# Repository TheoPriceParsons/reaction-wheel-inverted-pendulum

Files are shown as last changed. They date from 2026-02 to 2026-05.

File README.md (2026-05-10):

# Reaction-Wheel Inverted Pendulum

A reaction-wheel-actuated pendulum stabilised at its unstable upright equilibrium using a two-phase controller: bang-bang energy shaping for swing-up and a discrete LQR with Luenberger observer for stabilisation. Implemented on an STM32F446RE Nucleo running at 500 Hz using STM32 HAL.

> **Status:** Simulation complete. Hardware build in progress.

**TODO: UPDATE FIRMWARE WITH SIM CONSTANTS**

---

## Demo

*Video coming once hardware build is complete.*

Simulation result (30 s run, $\theta_0 = 0.1$ rad):

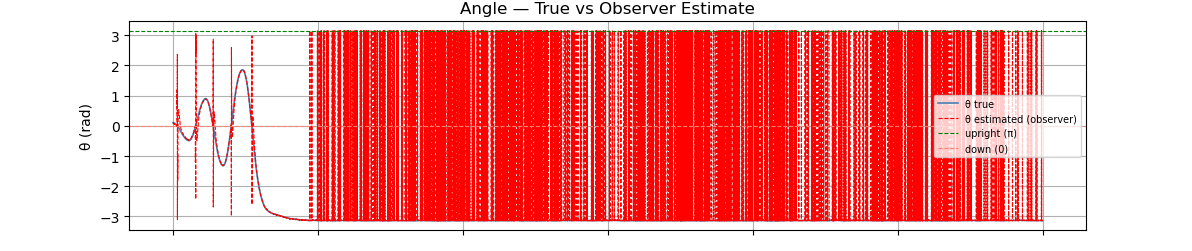
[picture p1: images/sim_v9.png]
Simulation


---

## Why This Problem Is Hard

The system has two degrees of freedom (pendulum angle $\theta$, wheel angle $\varphi$) but only one control input (motor torque $\tau$). This underactuation means a single controller cannot handle the full range of motion:

- **Large angles:** the linearisation breaks down entirely — $\sin\theta \neq \theta$
- **Near upright:** the equilibrium is open-loop unstable (eigenvalues $\pm 5.7$ rad/s)
- **No velocity sensor:** $\dot{\theta}$ is not directly measured; it must be estimated

A single LQR cannot swing the pendulum up from rest. A single energy controller cannot stabilise the upright. The solution requires two controllers and a principled switch between them.

---

## Controller Design

### Phase 1 — Bang-Bang Swing-Up

A bang-bang energy pump drives the pendulum from rest toward the upright equilibrium. The control law applies full motor voltage in the direction that adds mechanical energy:

$$
\tau = \begin{cases} -V_{\text{supply}} \cdot \text{sign}(\dot{\theta}) & \text{if } E < E^* \\ 0 & \text{if } E \geq E^* \end{cases}
$$

where $E^* = mgl$ is the target energy (upright with zero velocity) and the current energy is:

$$E = \tfrac{1}{2}ml^2\dot{\theta}^2 - mgl\cos\theta$$

Torque is cut once sufficient energy has accumulated; the pendulum coasts toward the top where LQR engages. A small initial kick ($0.3 \cdot V_{\text{supply}}$) handles the degenerate case where $\dot{\theta} \approx 0$ at startup.

### Phase 2 — Discrete LQR

Near the upright equilibrium, the nonlinear system is linearised by substituting $\delta = \theta - \pi$ (deviation from upright) and using $\sin(\pi + \delta) \approx -\delta$:

$$\ddot{\delta} \approx \frac{g}{l}\delta - \frac{2}{ml^2}\tau$$

This gives a 2-state controllable system $\mathbf{x} = [\delta,\; \dot{\delta}]^\top$. The LQR minimises:

$$J = \sum \left(\mathbf{x}^\top Q\mathbf{x} + R\tau^2\right)$$

with $Q = \text{diag}(300,\, 10)$, $R = 1$. The plant is discretised via zero-order hold at 500 Hz before solving the discrete algebraic Riccati equation.

**Why not design LQR on the full 3-state system $[\theta,\, \dot{\theta},\, \dot{\varphi}]$?** The controllability matrix of the full system has rank 2 — $\dot{\varphi}$ is uncontrollable from $\tau$. Including it in the LQR produces a spurious gain on an unobservable state.

### Switching Condition

LQR engages when both:
- $|\hat{\delta}| < 0.5$ rad (estimated deviation from upright)
- $|\dot{\hat{\delta}}| < 4.0$ rad/s (estimated angular velocity)

Estimates come from the Luenberger observer, not raw measurements.

### Luenberger Observer

The encoder measures $\theta$ with noise ($\sigma \approx 0.02$ rad). Angular velocity $\dot{\theta}$ is not directly sensed. A discrete Luenberger observer runs at 500 Hz alongside the controller:

$$
\begin{aligned}
\hat{\mathbf{x}}[k+1] &= A_d\hat{\mathbf{x}}[k] + B_d\tau[k] \quad \text{(prediction)}\\
\hat{\mathbf{x}}[k] &= \hat{\mathbf{x}}[k] + L\!\left(\delta_{\text{meas}} - \hat{x}_0[k]\right) \quad \text{(correction)}
\end{aligned}
$$

Observer poles are placed at $z = e^{-40\,\Delta t}$ and $z = e^{-60\,\Delta t}$ — roughly 3–5× faster than the closed-loop poles, following standard observer design rules. This gives the observer gain $L = [0.190,\; 4.562]^\top$.

The observer is what makes the LQR switching condition reliable. Using raw encoder position alone to decide when to switch would cause false triggers from measurement noise.

---

## Hardware

| Part | Qty | Notes |
|---|-----|---|
| STM32F446RE Nucleo-64 | 1 | Already owned |
| Pololu 9.7:1 Metal Gearmotor 25Dx63L mm HP 12V with 48 CPR Encoder (item #4842) | 1 | 9.68:1 gearbox, 4mm D-shaft output, integrated Hall effect quadrature encoder (464.64 CPR at output shaft) |
| Pololu Universal Aluminum Mounting Hub for 4mm Shaft, M3 Holes (item #1997) | 1 | Attaches reaction wheel to gearmotor output shaft via set screw |
| VNH5019 Motor Driver Carrier (Pololu item #1451) | 1 | Handles up to 12A continuous, recommended for HP 25D series |
| AMT103-V encoder kit | 1 | Quadrature A/B mode, DIP switch position 10 = 2048 PPR. Used at pivot to measure $\theta$. The -V suffix means it ships with all sleeve sizes (2–8 mm) — use the sleeve matching your pivot shaft |
| 12V 2A power supply | 1 | Start at 3V during bring-up |

### Physical Parameters

| Parameter | Value | Notes |
|---|---|---|
| Pendulum length $l$ | 0.1 m | Pivot to motor shaft center |
| Bob mass $m$ | 0.25 kg | Estimated; update from CAD once built |
| Wheel inertia $I_w$ | 0.0003 kg·m² | From Onshape mass properties |
| Damping $b$ | 0.01 N·m·s/rad | Viscous friction estimate |

### Motor Parameters (Pololu #4842, referred to output shaft)

| Parameter | Value | Source |
|---|---|---|
| $V_{\text{supply}}$ | 12.0 V | Rated |
| $R_m$ (winding resistance) | 2.4 Ω | $V / I_{\text{stall}} = 12.0 / 5.0$ |
| $K_t$ (torque constant) | 0.0762 N·m/A | $\tau_{\text{stall}} / I_{\text{stall}} = 0.3812 / 5.0$ |
| $K_e$ (back-EMF constant) | 0.0762 V·s/rad | $\approx K_t$ at output shaft |
| $\eta$ (gearbox efficiency) | 0.52 | Datasheet max efficiency |
| Stall torque @ 12V (effective) | 0.198 Nm | $\eta \cdot K_t \cdot V / R_m$ |

**These will be verified on hardware** before final controller tuning. $K_t$ in particular should be measured directly.

---

## Repository Structure

```
├── report.pdf                          Full derivation (Lagrangian, LQR, observer design)
├── simulations/
│   └── Sim_v9_added-discretization.ipynb   Simulation with plots
├── Software/
│   └── pendulum_main.ino               Older simple FOC implementation used as a basis
│   └── pendulum_main_arduino           All components for STM32 HAL abstraction level
└── README.md
```

### Simulation

```bash
pip install numpy scipy matplotlib control
```

### Firmware

Firmware is written in STM32 HAL. The Arduino implementation is left as a starting point reference.

## Firmware Constants

Gains from simulation v9 — to be recomputed once real $m$ and $I_w$ are confirmed from hardware:

```c
const float Kd[2]    = {-3.403565f, -0.605939f};
const float Ad[2][2] = {{1.000196f, 0.002000f}, {0.196213f, 1.000196f}};
const float Bd[2]    = {-0.001600f, -1.600105f};
const float Ld[2]    = {0.190356f,  4.561568f};
const float dt       = 0.0020f;  // 500 Hz
```

---

## Design Decisions

**Why a Luenberger observer rather than a complementary filter?**

A complementary filter on encoder + differentiated position is simple but introduces a tuning parameter (cutoff frequency) with no principled connection to the system dynamics. The Luenberger observer poles are placed explicitly relative to the closed-loop poles, and the gain derivation falls directly out of the same state-space framework used for the LQR. Everything stays consistent — physics and math throughout, no hand-tuned filters.

**Why encode $\theta$ at the pivot rather than use an IMU?**

A base encoder gives exact $\theta$ with no drift, no complementary filter, and no phase lag. The IMU approach (used in many student builds) requires careful filter tuning and introduces delay that degrades observer performance. The AMT103-V at 2048 PPR gives sub-0.2° resolution, well below the observer's assumed noise floor.

---

## Planned Extensions

- [ ] Hardware build and experimental validation
- [ ] Measure motor parameters ($K_t$, $K_e$, $R_m$) directly on hardware
- [ ] Characterise encoder noise floor (connects observer $\sigma_{\text{angle}}$ assumption to real data)
- [ ] Bare-metal STM32 HAL rewrite
- [ ] Swing-up controller refinement
- [ ] Extended Kalman Filter replacing Luenberger observer

---

## References

- [V. Hunter Adams — Reaction Wheel Pendulum Lab (Cornell)](https://vanhunteradams.com/Pico/ReactionWheel/ReactionWheel.html)
- [SimpleFOC Reaction Wheel Reference Project](https://github.com/simplefoc/Arduino-FOC-reaction-wheel-inverted-pendulum)
- [SimpleFOC Library Documentation](https://docs.simplefoc.com/)
- Åström & Furuta, *Swinging up a Pendulum by Energy Control* (1996)

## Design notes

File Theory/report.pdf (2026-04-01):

## Nonlinear Modeling, Control, and Estimation of an Underactuated Pendulum System

Theodore Price-Parsons

April 1, 2026

Abstract

This report develops a first-principles dynamic model of a reaction-wheel-actuated pendulum using Lagrangian mechanics. A state-space representation is derived and used to design a Linear Quadratic Regulator (LQR) for stabilisation near the unstable upright equilibrium. A bang-bang energy-shaping controller handles the swing-up phase. Simulation results confirm stable regulation from the downward resting position.

## 1 Problem Statement

### 1.1 System Description

A rigid pendulum is mounted on a pivot and actuated by a reaction wheel attached at its tip. The wheel is driven by a motor that applies an internal torque τ between the pendulum body and the wheel. By Newton’s third law, this torque acts equally and oppositely on both components. The system is planar and the only external force is gravity.

### 1.2 Objective

Develop a first-principles dynamic model using Lagrangian mechanics, derive a state-space representation suitable for control design, and implement a two-phase controller: (1) a bang-bang energy pump to swing the pendulum from rest to near the upright position, and (2) an LQR to stabilise the upright unstable equilibrium.

### 1.3 Why the Problem Is Nontrivial

Three sources of difficulty make this problem non-trivial:

- Nonlinearity. The governing equation contains sin θ, which is only linear near equilibrium. A linear controller alone cannot handle large-angle motion.
- Underactuation. The system has two degrees of freedom (θ and ϕ) but only one control input (τ ). The wheel angle ϕ is not independently controllable.
- Unstable equilibrium. The upright position is open-loop unstable. Any perturbation causes the pendulum to fall without active control.

## 2 Physical Model

### 2.1 Convention

Throughout this report the following angle convention is used, consistent with the simulation:

Value | Physical meaning
θ = 0 | Pendulum hanging down (stable equilibrium)
θ = π | Pendulum pointing up (unstable equilibrium, control target)

This is the natural physical convention: gravity acts to restore the pendulum toward θ = 0.

### 2.2 Assumptions

- Massless and rigid pendulum rod
- No friction, no air resistance (ideal case; extensions in Section 6)
- Planar motion only
- Ideal motor: torque τ is applied instantaneously and without loss
- Gravitational acceleration g is constant

### 2.3 Generalised Coordinates

Symbol | Description | Convention
θ | Pendulum angle measured from downward vertical | θ = 0 is down
ϕ | Reaction wheel angle relative to the pendulum body

The absolute angular position of the reaction wheel in the inertial frame is θ + ϕ.

### 2.4 Parameters

Symbol | Description | Value used
m | Pendulum bob mass | 0.5 kg
l | Pendulum length | 0.3 m
Iw | Wheel moment of inertia | 0.002 kg m²
g | Gravitational acceleration | 9.81 m/s²

## 3 Equations of Motion

### 3.1 Kinetic Energy

The system has two contributions to kinetic energy. Pendulum bob (point mass, translational):

Tpend =

1
2

ml² ˙θ
2

Reaction wheel (rotational about pivot):

Twheel =

1
2

Iw

˙θ + ϕ˙

2

Total kinetic energy:

T =

1
2

ml² ˙θ
2 +

1
2

Iw

˙θ + ϕ˙

2

### 3.2 Potential Energy

With θ = 0 defined as the downward position, the bob is at its lowest point when θ = 0 and at its highest when θ = π. The potential energy is:

V = −mgl cos θ

Verification:

- θ = 0 (down): V = −mgl | (minimum, stable) ✓
- θ = π (up): V = +mgl | (maximum, unstable) ✓

### 3.3 Lagrangian

L = T − V =

| 1
| 2 ml² ˙θ 2 +
| 1
| 2 Iw
˙θ + ϕ˙

2
+ mgl cos θ

### 3.4 Euler–Lagrange Equations

Applying the Euler–Lagrange equation to each generalised coordinate qi :

| d

dt
∂L
∂q˙i
−

∂L
∂qi

= Qi

The motor applies torque τ internally between the pendulum and the wheel. By Newton’s third law, the generalised forces are:
Qθ = −τ, Qϕ = +τ

For θ:
(ml² + Iw)

¨θ + Iwϕ¨ − mglsin θ = −τ

For ϕ:
Iw(

¨θ + ϕ¨) = τ

Note the sign on sin θ: with V = −mgl cos θ, the partial derivative ∂V /∂θ = mglsin θ enters with a negative sign in the Euler–Lagrange equation, giving −mglsin θ on the left-hand side. This is consistent with a restoring force toward θ = 0.

### 3.5 Solving for Accelerations

From the ϕ equation:
ϕ¨ =

τ
Iw

− ¨θ

Substituting into the θ equation and simplifying:

¨θ = −

g
l

sin θ −

2
ml²

τ

ϕ¨ =

τ
Iw

+

g
l

sin θ +

2
ml²

τ

Physical check: with τ = 0 (no control):

- Near θ = 0 (down): sin θ ≈ θ, so ¨θ ≈ −(g/l)θ < 0 for θ > 0. Restoring. Stable. ✓
- Near θ = π (up): let δ = θ − π, then sin θ = sin(π + δ) ≈ −δ, so ¨θ ≈ +(g/l)δ. Diverging. Unstable. ✓

## 4 State-Space Formulation

### 4.1 Reduction to Two States

Although the full system has three states [θ, ˙θ, ϕ˙

], note that ϕ˙ does not appear in the ¨θ equation. The controllability matrix of the full 3 × 3 system has rank 2: the ϕ˙ direction is uncontrollable. Applying LQR to the full system produces a spurious gain on ϕ˙ that has no physical effect on the pendulum angle.
The correct approach is to design the LQR on the controllable subsystem:

x =

δ
˙δ
, δ = θ − π

where δ is the deviation from the upright equilibrium, wrapped into [−π, π].

### 4.2 Linearisation around Upright (θ = π)

Near upright, sin(π + δ) ≈ −δ, so:
¨δ ≈

g
l

δ −

| 2 ml² τ

The linearised state-space model is:

x˙ = Ax + Bτ, A =

"
0 1
g
l

0

, B =

"
0
−

2
ml²

Eigenvalues of A: λ = ±

p
g/l ≈ ±5.72 rad/s. The positive eigenvalue confirms open-loop instability at the upright equilibrium.

## 5 Control Design

### 5.1 Overview: Two-Phase Strategy

The controller switches between two modes based on proximity to the upright equilibrium:

1. Swing-up (large angles): bang-bang energy pump
2. Stabilisation (near upright): LQR

Switching condition: engage LQR when |δ| < 0.3 rad and |

˙δ| < 2.0 rad/s.

### 5.2 LQR Stabilisation

The LQR minimises the cost functional:

J =

Z ∞

0

x

⊤Qx + Rτ ²

dt

with weighting matrices:

Q =

300 | 0
0 | 10
, | R = 1

The feedback law is τ = −Kx where K is the solution to the algebraic Riccati equation. The high weight on δ relative to ˙δ prioritises angle correction over velocity damping.

### 5.3 Bang-Bang Swing-Up

The LQR is only valid near the upright equilibrium. For large angles, a bang-bang energy pump is used:

τ =

(

umax · sgn
˙θ cos(θ − π)
if E < E∗
0 | if E ≥ E∗

where the target energy is E∗ = mgl (upright with zero velocity) and the current energy is:

E =

1
2

ml² ˙θ
| 2 − mgl cos θ

The sign term ˙θ cos(θ − π) is positive when motion is directed toward the upright position, ensuring torque always adds energy rather than opposing it. When sufficient energy has been accumulated (E ≥ E∗
), torque is cut to zero and the pendulum coasts toward the top where LQR engages.
This formulation avoids two failure modes of the standard ˚Astr¨om energy-shaping law: (1) zero torque at startup due to the ˙θ factor, and (2) zero torque at the horizontal position where cos(δ) = 0.

## 6 Planned Extensions

### 6.1 Viscous Friction

Add a damping term to the equation of motion:

¨θ = −

g
l

sin θ −

b
ml²

˙θ −

2
ml²

τ

where b is a viscous damping coefficient. This reduces available energy per swing and tests whether the bang-bang controller has sufficient authority.

### 6.2 Motor Back-EMF

Replace the ideal torque input with a motor electrical model:

τ = Kt

- I, I =

Vapplied − Keϕ˙

Rm

where Kt

is the torque constant, Ke the back-EMF constant, and Rm the winding resistance. This caps available torque at high wheel speeds and couples the electrical and mechanical dynamics.

### 6.3 State Estimation

Real sensors provide noisy measurements. An Extended Kalman Filter (EKF) or Luenberger observer will be added to estimate [θ, ˙θ] from corrupted measurements before implementation on hardware.

### 6.4 Hardware Implementation

Target platform: STM32 F446RE Nucleo board (180 MHz Cortex-M4 with FPU). Sensing via IMU (MPU6050) with complementary filter for angle estimation. Control loop target: 500–1000 Hz via hardware timer interrupt.

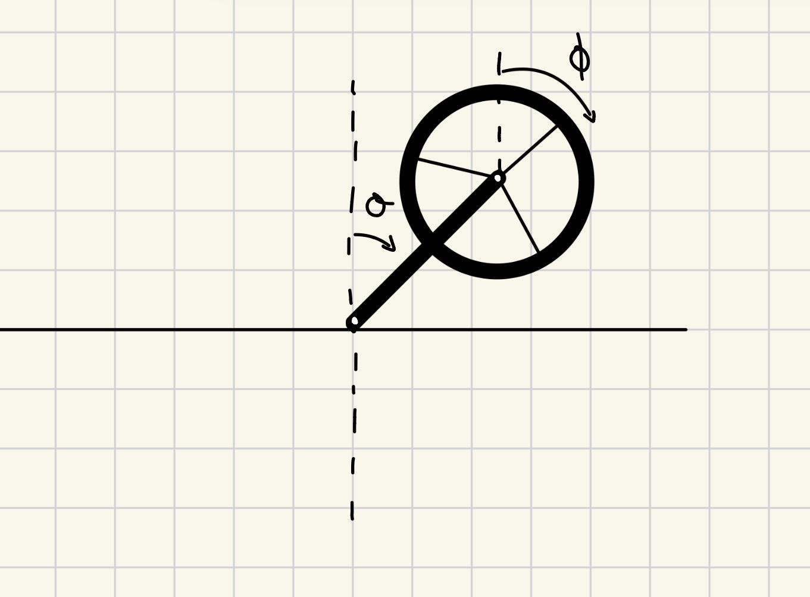
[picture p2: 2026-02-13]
images/Presentation_image.jpeg

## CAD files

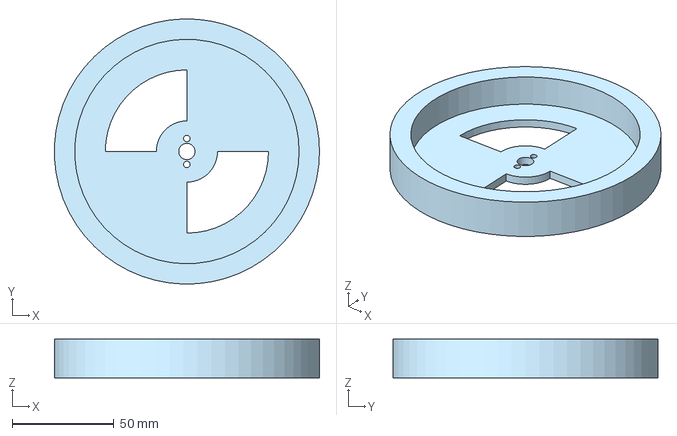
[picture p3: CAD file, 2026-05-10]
CAD/Reaction_wheel.step
129.9 x 130.0 x 19.0 mm

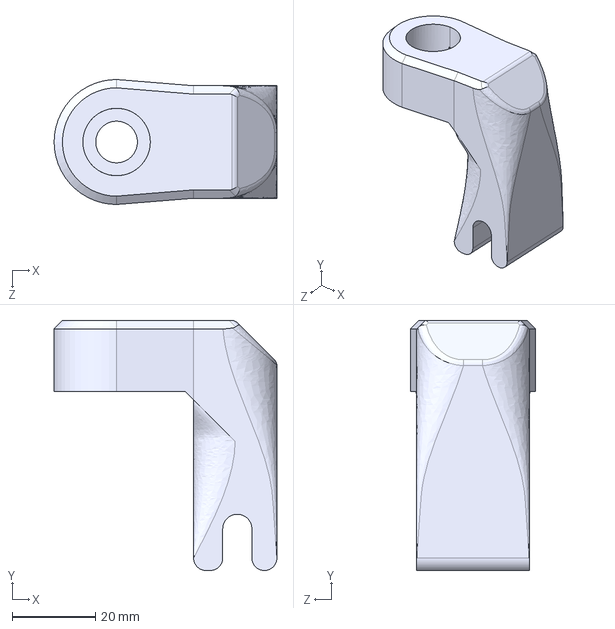
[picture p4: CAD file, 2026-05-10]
CAD/bottom_swingup.STEP
53.5 x 60.0 x 30.0 mm

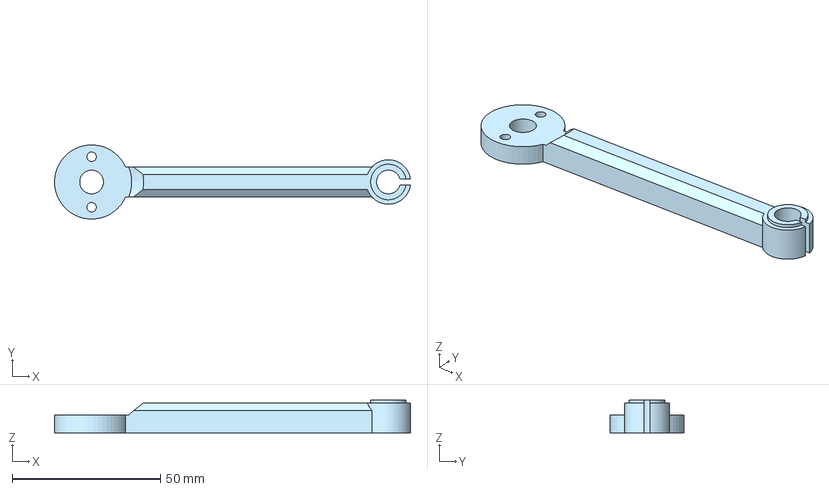
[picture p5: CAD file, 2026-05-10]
CAD/arm_pendulum.step
119.9 x 25.0 x 11.0 mm

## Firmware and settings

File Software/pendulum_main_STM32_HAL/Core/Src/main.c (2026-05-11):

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
/* Includes ------------------------------------------------------------------*/
#include "main.h"

/* USER CODE BEGIN Includes */
#include <math.h>
#include <stdlib.h>
#include <string.h>
#include <stdio.h>
/* USER CODE END Includes */

/* USER CODE BEGIN PD */
#define DT   0.002f
#define V_SUPPLY 3.0f   // change to 12.0f V
//physics sims constants
#define G       9.81f
#define M_PEND  0.5f
#define L       0.3f
#define R_M     2.4f
#define K_E     0.00954f
#define K_T     0.03f
#define DELTA_SW      0.5f
#define DELTA_DOT_SW  4.0f
/* USER CODE END PD */

TIM_HandleTypeDef htim1;
TIM_HandleTypeDef htim2;
TIM_HandleTypeDef htim3;
TIM_HandleTypeDef htim4;

UART_HandleTypeDef huart2;
DMA_HandleTypeDef hdma_usart2_tx;

void SystemClock_Config(void);
static void MX_GPIO_Init(void);
static void MX_DMA_Init(void);
static void MX_USART2_UART_Init(void);
static void MX_TIM1_Init(void);
static void MX_TIM3_Init(void);
static void MX_TIM4_Init(void);
static void MX_TIM2_Init(void);
/* USER CODE BEGIN PFP */
void HAL_TIM_PeriodElapsedCallback(TIM_HandleTypeDef *htim);
void setMotor(float Vcmd);
static inline float wrap(float angle);
/* USER CODE END PFP */

/* USER CODE BEGIN 0 */
//control loop constant
volatile uint8_t doControl = 0;
//gains from sim
const float Kd[2] = {-4.976694f, -1.404655f};
const float Ad[2][2] = {{1.000065f, 0.002000f}, {0.065401f, 1.000065f}};
const float Bd[2]    = {-0.000089f, -0.088891f};
const float Ld[2]    = {0.190094f,  4.418506f};
/* USER CODE END 0 */

/**
  * @brief  The application entry point.
  * @retval int
  */
int main(void)
{

  /* USER CODE BEGIN 1 */
	float x_hat[2]   = {-M_PI, 0.0f};
	float V_prev     = 0.0f;
	float omega_prev = 0.0f;
  /* USER CODE END 1 */

  /* MCU Configuration--------------------------------------------------------*/

  /* Reset of all peripherals, Initializes the Flash interface and the Systick. */
  HAL_Init();

  /* Configure the system clock */
  SystemClock_Config();

  /* Initialize all configured peripherals */
  MX_GPIO_Init();
  MX_DMA_Init();
  MX_USART2_UART_Init();
  MX_TIM1_Init();
  MX_TIM3_Init();
  MX_TIM4_Init();
  MX_TIM2_Init();
  /* USER CODE BEGIN 2 */
  HAL_TIM_Base_Start_IT(&htim3);
  HAL_TIM_PWM_Start(&htim1, TIM_CHANNEL_1);
  HAL_TIM_Encoder_Start(&htim2, TIM_CHANNEL_ALL);
  HAL_TIM_Encoder_Start(&htim4, TIM_CHANNEL_ALL);
  // = awake for the sleep pin
  HAL_GPIO_WritePin(GPIOB, GPIO_PIN_4, GPIO_PIN_SET);
  /* USER CODE END 2 */

  /* Infinite loop */
  /* USER CODE BEGIN WHILE */
  while (1)
  {
	  if (doControl) {
		  doControl=0;
		  //previous tau
		  float tau_prev = K_T * (V_prev - K_E * omega_prev) / R_M;
		  //we measure theta
		  int16_t count = (int16_t)TIM4->CNT;
		  float theta = ((float)count/(2048.0f * 4.0f))*2.0f*M_PI;
		  float delta_meas = wrap(theta - M_PI);
		  //we measure Omega
		  int32_t raw = (int32_t)TIM2->CNT;
		  float omega = ((float)raw / 48.0f) * (2.0f * M_PI) / DT;
		  TIM2->CNT = 0;
		  //sim + control
		  float x_hat_new[2];
		  x_hat_new[0] = Ad[0][0]*x_hat[0] + Ad[0][1]*x_hat[1] + Bd[0]*tau_prev;
		  x_hat_new[1] = Ad[1][0]*x_hat[0] + Ad[1][1]*x_hat[1] + Bd[1]*tau_prev;
		  x_hat[0] = x_hat_new[0];
		  x_hat[1] = x_hat_new[1];
		  //we correct with our out of house L constant from sim
		  float innov = delta_meas-x_hat[0];
		  x_hat[0] = x_hat[0] + Ld[0]*innov;
		  x_hat[1] = x_hat[1] + Ld[1] * innov;
		  //LQR or Bang Bang?
		  //energy for bang bang
		  float E = 0.5f * M_PEND * L * L * x_hat[1] * x_hat[1] - M_PEND * G * L * cosf(theta);
		  //our goal
		  float E_star = M_PEND * L * G;
		  //Bang Bang voltage:
		  float V_su;
		  if (fabsf(x_hat[1])<1e-6f) {
		        V_su = 0.3f*V_SUPPLY;
		   }
		   else if (E<E_star) {
		        V_su = -V_SUPPLY*x_hat[1]/(fabsf(x_hat[1]));
		   }
		   else {
		        V_su = 0;
		   }
		   //LQR
		   float tau_lqr_des = -(Kd[0] * x_hat[0] + Kd[1] * x_hat[1]);
		   float V_lqr = (tau_lqr_des/K_T)*R_M + K_E * omega;
		   //we choose
		   float V_cmd;
		   if (fabsf(x_hat[0])<DELTA_SW && fabsf(x_hat[1])<DELTA_DOT_SW) {
		        V_cmd=V_lqr;
		    }
		    else {
		        V_cmd = V_su;
		    }
		   setMotor(V_cmd);
		   omega_prev = omega;
		   V_prev = V_cmd;
		   static char buf[64];
		   static uint8_t uart_div = 0;
		   if (++uart_div >= 10) {
		       uart_div = 0;
		       int len = snprintf(buf, sizeof(buf), "%.3f,%.3f,%.3f,%.3f\r\n",
		                          delta_meas, x_hat[1], omega, V_cmd);
		       HAL_UART_Transmit_DMA(&huart2, (uint8_t*)buf, len);
		   }

	  }
    /* USER CODE END WHILE */

    /* USER CODE BEGIN 3 */
  }
  /* USER CODE END 3 */
}

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
/* USER CODE BEGIN 4 */
void HAL_TIM_PeriodElapsedCallback(TIM_HandleTypeDef *htim)
	{

		if (htim->Instance == TIM3)
		{
			doControl=1;
		}
}
void setMotor(float Vcmd){
	Vcmd=fmaxf(-V_SUPPLY,fminf(V_SUPPLY,Vcmd));
	uint32_t duty = (uint32_t)(fabsf(Vcmd)/V_SUPPLY*8999.0f);
	if (Vcmd>0.0f) {
		HAL_GPIO_WritePin(GPIOB, GPIO_PIN_10, GPIO_PIN_SET);//INA
		HAL_GPIO_WritePin(GPIOB, GPIO_PIN_2,  GPIO_PIN_RESET);//INB
	}
	else {
		HAL_GPIO_WritePin(GPIOB, GPIO_PIN_10, GPIO_PIN_RESET);//INA
		HAL_GPIO_WritePin(GPIOB, GPIO_PIN_2,  GPIO_PIN_SET);//INB
	}
	__HAL_TIM_SET_COMPARE(&htim1, TIM_CHANNEL_1, duty);

}
static inline float wrap(float angle) {
	    while (angle > M_PI)  angle -= 2.0f * M_PI;
	    while (angle < -M_PI) angle += 2.0f * M_PI;
	    return angle;
	}
/* USER CODE END 4 */
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


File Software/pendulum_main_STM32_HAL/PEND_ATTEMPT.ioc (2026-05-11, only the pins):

Mcu.UserName=STM32F446RETx
PA0-WKUP.Signal=S_TIM2_CH1_ETR
PA1.Signal=S_TIM2_CH2
PA13.GPIO_Label=TMS
PA13.Signal=SYS_JTMS-SWDIO
PA14.GPIO_Label=TCK
PA14.Signal=SYS_JTCK-SWCLK
PA2.GPIO_Label=USART_TX
PA2.Signal=USART2_TX
PA3.GPIO_Label=USART_RX
PA3.Signal=USART2_RX
PA5.GPIO_Label=LD2 [Green Led]
PA5.Signal=GPIO_Output
PA8.Signal=S_TIM1_CH1
PB10.Signal=GPIO_Output
PB2.Signal=GPIO_Output
PB3.GPIO_Label=SWO
PB3.Signal=SYS_JTDO-SWO
PB4.Signal=GPIO_Output
PB6.Signal=S_TIM4_CH1
PB7.Signal=S_TIM4_CH2
PC13.GPIO_Label=B1 [Blue PushButton]
PC13.Signal=GPXTI13
PC14-OSC32_IN.Signal=RCC_OSC32_IN
PC15-OSC32_OUT.Signal=RCC_OSC32_OUT
PH0-OSC_IN.Signal=RCC_OSC_IN
PH1-OSC_OUT.Signal=RCC_OSC_OUT

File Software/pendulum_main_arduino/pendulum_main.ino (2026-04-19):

#include <SimpleFOC.h>
#include <math.h>
#include <stdlib.h>
//physical constants
#define M_PI     3.14159265358979f
//#define V_SUPPLY 12.0f
#define V_SUPPLY 3.0f//for set up
#define G        9.81f
#define M_PEND   0.5f
#define L        0.3f
#define IW       0.002f
#define B_DAMP   0.01f
//motor constants
#define R_M      2.4f
#define K_E      0.00954f
#define K_T      0.03f
//Gains from jupyter sims
#define DT       0.002f
const float Kd[2] = {-4.976694f, -1.404655f};
const float Ad[2][2] = {{1.000065f, 0.002000f}, {0.065401f, 1.000065f}};
const float Bd[2]    = {-0.000089f, -0.088891f};
const float Ld[2]    = {0.190094f,  4.418506f};
//switching threshholds
#define DELTA_SW     0.5f
#define DELTA_DOT_SW 4.0f
//FOC objects:
  BLDCMotor  motor(11);  // 11 pole pairs
  BLDCDriver3PWM driver(PA8, PA9, PA10);  // 3-phase

//Encoder on motor shaft
  Encoder enc_motor(PB4, PB5, 2048);
  void doMotorA() { enc_motor.handleA(); }
  void doMotorB() { enc_motor.handleB(); }

// Encoder on the pendulum gives us theta
  Encoder enc_pivot(PB6, PB7, 2048);
  void doPivotA() { enc_pivot.handleA(); }
  void doPivotB() { enc_pivot.handleB(); }

//initialising the observer vars
float x_hat[2]   = {0.0f, 0.0f};
float V_prev     = 0.0f;
float omega_prev = 0.0f;
//loop control we are running 500Hz so loop runs every 2ms
volatile uint32_t last_time = 0;


void setup() {
  Serial.begin(115200);
  //motor
  enc_motor.init();
  enc_motor.enableInterrupts(doMotorA, doMotorB);
  //pendulum
  enc_pivot.init();
  enc_pivot.enableInterrupts(doPivotA, doPivotB);
  //linking them up
  motor.linkDriver(&driver);
  motor.linkSensor(&enc_motor);
  motor.voltage_limit = V_SUPPLY;//caution start at 3V
  //Initializing...
  driver.init();
  motor.init();
  motor.initFOC();
  

}

//helper functions
float wrap(float angle) {
  return fmodf(angle+M_PI,2.0f * M_PI) - M_PI;
}
void loop() {
  motor.loopFOC();
  // put your main code here, to run repeatedly:(every 2ms)
  if (micros()-last_time>=2000) {
    last_time += 2000;
    //read the encoder motor and pendulum
    float theta = enc_pivot.getAngle();
    float delta_meas = wrap(theta-M_PI);
    float omega = enc_motor.getVelocity();
    float tau_prev = K_T * (V_prev - K_E * omega_prev) / R_M;
    float theta_dot = enc_pivot.getVelocity();
    //We estimate with sim calcs with model
    float x_hat_new[2];
    x_hat_new[0] = Ad[0][0]*x_hat[0] + Ad[0][1]*x_hat[1] + Bd[0]*tau_prev;
    x_hat_new[1] = Ad[1][0]*x_hat[0] + Ad[1][1]*x_hat[1] + Bd[1]*tau_prev;
    x_hat[0] = x_hat_new[0];
    x_hat[1] = x_hat_new[1];
    //we correct with our out of house L constant from sim
    float innov = delta_meas-x_hat[0];
    x_hat[0] = x_hat[0] + Ld[0]*innov;
    x_hat[1] = x_hat[1] + Ld[1] * innov;
    //LQR or Bang Bang?
    //energy for bang bang
    float E = 0.5f * M_PEND * L * L * theta_dot * theta_dot - M_PEND * G * L * cosf(theta);
    //our goal
    float E_star = M_PEND * L * G;
    //Bang Bang voltage:
    float V_su;
    if (fabsf(theta_dot)<1e-6f) {
      V_su = 0.3f*V_SUPPLY;
    }
    else if (E<E_star) {
      V_su = -V_SUPPLY*theta_dot/(fabsf(theta_dot));
    }
    else {
      V_su = 0;
    }
    //LQR
    float tau_lqr_des = -(Kd[0] * x_hat[0] + Kd[1] * x_hat[1]);
    float V_lqr = (tau_lqr_des/K_T)*R_M + K_E * omega;
    //we choose
    float V_cmd;
    if (fabsf(x_hat[0])<DELTA_SW && fabsf(x_hat[1])<DELTA_DOT_SW) {
      V_cmd=V_lqr;
    }
    else {
      V_cmd = V_su;
    }
    //we tell FOC what torque we want
    V_cmd = constrain(V_cmd, -V_SUPPLY, V_SUPPLY);
    motor.move(V_cmd);
    //we keep it for the next time around
    omega_prev = omega;
    V_prev = V_cmd;
  }

}

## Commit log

2026-04-26 add HAL STM32 skeleton code
2026-05-10 updated sim and added CAD as first prototypes
    [Reaction_wheel.step, arm_pendulum.step, bottom_swingup.STEP]
2026-05-11 updating PWM with new driver

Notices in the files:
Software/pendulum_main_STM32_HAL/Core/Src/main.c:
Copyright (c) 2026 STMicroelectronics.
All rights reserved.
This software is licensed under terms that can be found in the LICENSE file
